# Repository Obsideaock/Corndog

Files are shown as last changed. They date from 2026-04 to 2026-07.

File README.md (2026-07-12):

# Project Corndog







> An open-source quadruped robot designed to make robotics accessible — one walking robot at a time.

Corndog Walking

Corndog started as a workaround to a college rule (no drones on campus → build a walking robot instead) and turned into a nearly two-year deep dive into robotics, kinematics, and control systems. Based on the open-source MicroSpot design and inspired by Boston Dynamics' Spot, it's a small quadruped with 3 degrees of freedom per leg, a full inverse kinematics stack, IMU feedback, and a growing set of behaviors.

**As featured on American Ninja Warrior Season 17**

---

## Current Status

| Feature | Status |
|---|---|
| Static walking gaits (forward/backward) | ✅ Working |
| Turn left / turn right | ✅ Working |
| Standing & balancing | ✅ Working |
| Inverse kinematics (IK) | ✅ Working |
| IMU feedback (BNO08X) | ✅ Working |
| Custom animations (dance, wave, handstand, etc.) | ✅ Working |
| Companion mode (shoulder perch) | ✅ Working |
| Steam Deck wireless control + video stream | ✅ Working |
| Dynamic gaits | 🔧 In progress |
| ML-Agents gait learning | 🔧 In progress (environment skeleton done) |
| Custom power PCB | 🔧 In progress |
| Kit available for purchase | 🔜 Coming soon |
| Assembly guide | 🔜 In progress |

---

## Build at a Glance

| Spec | Value |
|---|---|
| Size | ~15 inches |
| Legs | 4 (quadruped) |
| Degrees of freedom | 12 total (3 per leg) |
| Brain | Raspberry Pi 5 |
| Servo driver | Adafruit PCA9685 |
| Actuation range | 0–270° per servo |
| Power | LiPo battery + buck converter (custom PCB coming) |
| Construction | 3D printed (PLA) |
| Control | Tkinter GUI on-device, or Steam Deck over TCP |

---

## Estimated Cost

Corndog is open-source — you can print and source everything yourself. If you'd rather skip the work, a kit is coming soon through [OpenLonehollow](https://openlonehollow.com/Projects/corndog/corndog.html).

| Tier | What You Get | Estimated Price |
|---|---|---|
| **Printed Parts Only** | All 3D printed structural components | ~$60–80 |
| **Unassembled Kit** | Printed parts + all electronics | ~$450–500 |
| **Assembled & Calibrated** | Fully built, programmed, and ready to go | ~$800 |

Want to build it yourself from scratch? Everything you need is in this repo and the [assembly guide](https://openlonehollow.com/Projects/corndog/assembly-guide/index.html).

---

## Hardware

| Component | Notes | Example Link |
|---|---|---|
| Raspberry Pi 5 | Raspbian 64-bit | [Amazon](https://a.co/d/dEzpuJt) |
| Adafruit PCA9685 PWM Driver | I²C address 0x40 | [Adafruit](https://www.adafruit.com/product/815) |
| Servo Motors × 12 | 0–270°, pulse 500–2500 µs | [Amazon](https://a.co/d/4C4s5K8) |
| Adafruit BNO08X IMU | I²C address 0x4B | — |
| LiPo Battery + Power Module | Custom PCB solution coming | [Amazon](https://a.co/d/3LN6lL5) |
| I²C LCD Display | For status readout | — |
| Wires, headers, standoffs | Standard hobby hardware | — |

> A full Bill of Materials with exact quantities and sources is in progress and will be linked here.

---

## 3D Printed Parts

Most structural parts come from [KDY0523's Thingiverse design](https://www.thingiverse.com/thing:3445283), with reinforced legs from [mike4192's SpotMicro fork](https://github.com/mike4192/spotMicro).

Modifications and custom parts (like the shoulder harness for companion mode) are included in the `/3DModels` folder.

- All parts currently printed in **PLA**
- Experimented with ASA for joints (more strength) but it snapped under stress and PLA is easier to work with
- Thanks to **BTULab (where I work now) @ CU Boulder** for printing assistance

---

## Installation

Everything installs itself. On a fresh Raspberry Pi (Raspberry Pi OS
Bookworm 64-bit with desktop), open a terminal on the Pi and run:

```bash
curl -sSL https://raw.githubusercontent.com/Obsideaock/Corndog/main/installer/install.sh | bash
sudo reboot
```

That single line handles the apt packages, I2C, the Python environment,
the IK library, the `corndog` command, and the boot supervisor. To install
somewhere other than `~/Corndog`:

```bash
curl -sSL https://raw.githubusercontent.com/Obsideaock/Corndog/main/installer/install.sh | CORNDOG_DIR=/path/you/want bash
```

Full details in [Docs/USER_GUIDE.md](Docs/USER_GUIDE.md).

---

## Key Scripts

| Script | What it does |
|---|---|
| `main.py` | Core control: IK, all movements, Tkinter GUI |
| `SteamDeckCommunication.py` | Joystick control over TCP + MJPEG video stream |
| `MoveLib.py` | Movement library (aliased by SteamDeck script) |
| `gait_engine_app.py` | Gait engine module |
| `StartupLCD.py` | Boot supervisor + LCD display |
| `tools/align.py` | Assembly Part A: hold servos at the horn pose |
| `tools/calibrate.py` | Assembly Part B: trim joints + save calibration |
| `Flipper2.py` / `FlipperTed.py` | Flipper Zero integration |

---

## Setup & Calibration

Calibration is built in — no more editing angles by hand. During assembly:

```bash
corndog align       # Part A: before horns go on — holds every servo at
                    # the reference pose so you attach horns correctly
corndog calibrate   # Part B: after assembly, robot ON ITS BACK — nudge
                    # each joint to perfect, press s to save
```

The calibration lives in `~/.config/corndog/calibration.json` and survives
every software update. Details in
[Docs/USER_GUIDE.md](Docs/USER_GUIDE.md).

**Run**
```bash
corndog gui                 # GUI control (on-device)
corndog deck                # Steam Deck / remote control + video stream
# Stream available at http://<pi-ip>:8000/stream.mjpg
# Control on TCP port 65432
```

---

## Roadmap

- [x] Static walking gaits
- [x] Turn left / right
- [x] Inverse kinematics
- [x] IMU integration
- [x] Companion mode
- [x] Steam Deck control
- [ ] Assembly guide (in progress)
- [ ] Full BOM
- [ ] Custom power PCB
- [ ] Dynamic gaits
- [ ] ML-Agents gait training
- [ ] Web dashboard
- [ ] Kit launch

---

## Contributing

Issues and PRs are welcome — please use [GitHub Issues](https://github.com/Obsideaock/Corndog/issues) and follow existing code style. The project is licensed [CC BY 4.0](https://creativecommons.org/licenses/by/4.0/), so use and adapt freely with credit.

---

## Acknowledgements

- **[KDY0523](https://www.thingiverse.com/thing:3445283)** — original 3D design
- **[Mike4192](https://github.com/mike4192/spotMicro)** — reinforced legs and IK library
- **[BTULab @ CU Boulder](https://www.colorado.edu/atlas/btu-lab)** — 3D printing support

---

*Built by [Leo Heuring (Obsideaock)](https://openlonehollow.com) · [openlonehollow.com](https://openlonehollow.com)*

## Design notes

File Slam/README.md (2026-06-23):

# Corndog SLAM (v2.3)

Pure-Python 2D LiDAR SLAM for the Corndog quadruped. No ROS. Builds a live
occupancy-grid map and tracks where Corndog is on it while you walk it around.

Hector-style scan-to-map matching (the approach proven on the mike4192 SpotMicro
with an RPLidar A1), reimplemented in pure numpy and fused with your **BNO08x**
heading and the **gait engine's commanded velocity** as a motion prior.
Validated in simulation before any hardware: on a simulated two-room walk it
reconstructs the floorplan and tracks the path to ~12 cm mean error — a 92%
reduction vs dead-reckoning, at ~3x less CPU per scan than v1.

**v2.0 adds point-and-click navigation:** open the map in a browser, click a
spot, and Corndog plans a path (A* with adjustable wall clearance), drives there
following it, hard-stops for anything that appears in front, and arrives within
~10 cm. Plus a new canvas UI (pan/zoom, STOP, named "spots"), a 35x24 cm oriented
footprint box, and one-time relocalization when you resume a saved map.

**v2.1 adds keep-out awareness, autonomy, and a phone-friendly UI:**

- **No-go zones** — switch the UI to *No-go* mode and drag a box over anything
  that looks clear to the LiDAR but isn't safe (rugs, carpets, ledges). Zones are
  saved next to the map (`<map>.nogo.json`), so they persist across restarts, and
  the planner refuses to route through them. *Clear no-go* wipes them.
- **Stuck detection** — if Corndog is commanded forward but his SLAM pose barely
  advances for ~1.6 s, he assumes there's an unmapped obstacle, stamps a small
  keep-out blob just ahead (it joins the same persistent layer, shown in orange),
  backs up briefly, and re-plans around it.
- **Roam** — a toggle that sends him to random *reachable* spots (respecting the
  clearance), biased toward places he hasn't been recently. He only picks spots
  *connected to where he currently is through mapped open space* — he won't try to
  reach a previously-seen area by cutting across unmapped/unknown space. Good for
  "just go wander the apartment."
- **Route loops** — *Route* mode: tap several stops, hit *Start loop*, and he
  cycles them in order, repeating.
- **Phone-friendly UI** — one-finger drag pans, **two-finger pinch zooms**, a tap
  acts; the page no longer hijack-zooms on mobile and the buttons grow on small
  screens.
- **Clearance is now 15 cm** by default (was 10 cm).
- **Reset map** button (UI) — wipes the map, trail, saved spots and no-go zones
  and starts a fresh map from where he's standing, without restarting the script.
  Handy for re-running a test.

A single explicit goal click always overrides roam/route.

**v2.2 adds loop closure (background pose-graph optimisation):** the frontend's
scan-to-map matching drifts slowly over long runs — you see it as walls that
don't quite line up when you return to a room. A background thread now drops a
*keyframe* (pose + scan) every ~0.5 m, ties consecutive ones with odometry edges,
and when a new keyframe lands near an old one it confirms the revisit with a
scan-to-scan match against a clean *local* field (so global drift can't fool the
check). A confirmed revisit adds a loop constraint; the SE(2) pose graph is then
optimised (pure-numpy Gauss-Newton, no scipy) and the map is rebuilt from the
corrected keyframe poses, with the live pose and heading nudged to match. This is
the main lever for turning "arrives within ~10 cm *on the map*" into "within
~10 cm *physically*" on long multi-loop runs. It runs only when a revisit is
detected, throttled so the Pi isn't taxed. It is **off by default** (it can
disturb live tracking); enable with `--loopclose`.

**v2.3 — drift control + adaptive navigation:**

- **Motion-gated mapping.** Localisation and obstacle detection run every frame as
  always, but the map is only *written* when the robot is essentially stopped (and
  never mid-turn). A moving scan — especially during a turn, when the spinning
  LiDAR builds one revolution over ~180 ms — smears, and committing it thickens
  walls and feeds drift. Gating the write keeps walls crisp and, because you then
  localise against crisp walls, slows drift too. Default is near-stationary;
  `--map-while-moving` also maps during straight travel (still skips turns).
  The HUD's `mapskip` counter shows writes being held while moving.
- **Adaptive re-planning.** The follower no longer tracks a path drawn once at the
  start. It recomputes to the goal on the *current* map every ~1.5 s and whenever
  blocked, so a stale path (new wall, closed door, drift) is corrected instead of
  driven into — e.g. it will route to the open space beside a wall rather than
  pushing into it.
- **Roam stays local.** Roam now picks goals within a radius (default 3 m) of where
  he is, so he wanders the area instead of bolting to a far room, and only to spots
  reachable through mapped open space.
- **Live SLAM readout** in the HUD: `SLAM Hz · match score · gated · mapskip`, for
  diagnosing tracking at a glance.

## Where this folder goes
Drop the whole `Slam/` folder into your main Corndog directory, next to
`MoveLib.py`:

```
Corndog/                      <- your main folder
  MoveLib.py
  SteamDeckCommunication.py
  ... your other files
  Slam/                       <- this folder
    run_robot.py              <- run this ON THE ROBOT
    run_laptop.py             <- run this ON A LAPTOP to test (no hardware)
    validate_sim.py           <- optional offline accuracy check
    README.md
    core.py  occupancy.py  scan_match.py  render.py  sim.py
    nav.py  relocalize.py  waypoints.py  keepout.py  web_server.py
    slam_bridge.py  slam_lidar.py  slam_map_server.py  slam_app.py
```

The slam code reaches up one level to import `MoveLib` and
`SteamDeckCommunication`, so it must stay inside the main Corndog folder.

## Run it

**On the robot (the Pi):**
```
cd Slam
python3 run_robot.py                 # SLAM + your Steam Deck control
python3 run_robot.py --no-control    # SLAM only, robot stays still
python3 run_robot.py --load corndog_map.npz   # resume + relocalize in a saved map
python3 run_robot.py --control keys           # drive from the terminal (WASD)
```
Then open `http://<pi-ip>:8001/` in a browser. **Click anywhere on the map to
send Corndog there**; drag to pan, wheel to zoom, big red **STOP** to halt. Save
the current position as a named "spot" and tap it later to go back. You can still
drive Corndog manually (Steam Deck) and it maps as you walk. With `--load`, it
spends a few seconds at startup figuring out where it is in the loaded map before
tracking takes over.

**On a laptop first (no hardware needed):**
```
cd Slam
python3 run_laptop.py                 # then open http://localhost:8001/
python3 validate_sim.py               # prints metrics, writes slam_sim_result.png
```
`run_laptop.py` uses the exact same map view as the robot, fed by a simulator.

## Install
On the Pi: `pip3 install pillow pyrplidar --break-system-packages` — this code
uses your SYSTEM numpy (1.x) and needs no scipy. **Do NOT pip-install numpy or
scipy on the Pi:** numpy 2.x breaks `picamera2`/`simplejpeg` (the camera stack).

If you already did (you'll see a `numpy.dtype size changed` error), revert with:
```
pip3 uninstall -y numpy scipy
sudo apt install --reinstall python3-numpy
```
(your BNO08x / adafruit deps are already there via MoveLib).
On a laptop (for the demo): `pip3 install numpy pillow`.

## What it does (v2.0)
- Live **5 cm occupancy grid**, log-odds, with free-space carving so people
  walking through fade instead of becoming permanent walls.
- Pose from **scan matching** seeded by IMU yaw + commanded velocity.
- **Tilt gating**: scans taken mid-stride (body pitch/roll past a threshold)
  don't corrupt the map.
- **Live web map** at `:8001` — robot dot + heading, live scan (cyan) vs mapped
  walls (white), ~30 s trajectory trail (amber).
- **Save / load** maps (`.npz`), autosave every 15 s.
- Runs in the **same process** as your Steam Deck control (single MoveLib import,
  no hardware contention).
- **Faster matcher** (v2): the likelihood field is rebuilt only in a window
  around the robot and the search is vectorised — ~3x less CPU per scan than v1,
  with equal-or-better accuracy.
- **Click-to-go navigation** (v2): A* over the map with a configurable clearance
  (`ROBOT_RADIUS_M + DEFAULT_CLEARANCE_M` in `nav.py`, ~10 cm default) so paths
  keep off walls; pure-pursuit follower; forward-cone **obstacle hard-stop** that
  pauses and resumes; arrives within ~10 cm. Goals on walls, in unknown space, or
  unreachable are rejected with a reason.
- **Canvas web UI** (v2): crisp (no JPEG re-encode, lighter than the old MJPEG),
  click-to-go, pan/zoom, STOP, named waypoints, planned-path overlay, and a
  **35 x 24 cm oriented footprint box** so you can judge what he'll clear.
- **Relocalization** (v2): on `--load`, a one-time global "where am I" search
  places him in the saved map from a single scan.
- **LiDAR auto-resync** (v2): the A1's occasional startup byte-mismatch now
  retries/reconnects automatically instead of needing a restart.

## Delivered in v2.1
No-go zones, stuck-detection with auto-obstacle + reroute, roam, route loops, the
phone-friendly UI, and 15 cm clearance (see the v2.1 summary up top). Roam covers
most of what "autonomous explore" was meant to do, and stuck-detection is a first
cut at dynamic re-routing around things the map didn't know about.

## Delivered in v2.2
**Loop closure + pose-graph optimisation** (see the v2.2 summary up top) — removes
the slow global drift on long multi-loop runs, the main thing between "arrives
within ~10 cm *on the map*" and "within ~10 cm *physically*."

## Next
Tighter integration of the loop-corrected map with relocalisation, and optional
sub-5 cm resolution (still deferred on purpose — compute budget — and won't change
silently).

## Bring-up calibration (once, on the robot)
Two sign conventions can't be known until it's on Corndog. Each is a one-line flip:

1. **Heading sense** — `YAW_SIGN` in `slam_bridge.py`. Turn Corndog ~90° left in
   place; if the map rotates the wrong way, set it to `-1.0`.
2. **LiDAR direction** — `LIDAR_CCW` in `slam_lidar.py`. If the map comes out
   mirrored (left/right flipped), toggle it. Use `ANGLE_OFFSET_DEG` if 0° isn't
   dead-ahead.
3. **Velocity scale** — `VEL_SCALE` in `slam_bridge.py`. Walk a measured 2 m; if
   the trail reads long/short, scale it. (Minor — the matcher fixes translation.)

Tilt gate (`tilt_gate_deg`, default 9°) and log-odds rates live in `core.py` /
`occupancy.py` for tuning to your gait.

## File map
```
core.py            SlamCore: motion prior + matching + map + trajectory (hardware-agnostic)
occupancy.py       log-odds grid, ray carving, save/load
scan_match.py      multi-res correlative scan matching + likelihood field
render.py          grid + overlays -> image (shared by web view + sim)
sim.py             hardware-free simulator (floorplan, foot-slip, body bob)
slam_bridge.py     [robot] BNO08x + gait engine -> motion hint
slam_lidar.py      [robot] RPLIDAR reader thread
nav.py             A* planner (15 cm clearance, keep-out aware) + pure-pursuit follower,
                   obstacle stop, route loops, roam, stuck-detection + reroute
relocalize.py      global "where am I" search for a loaded map
web_server.py      canvas/JSON web UI: Go / Route / No-go modes, Roam toggle, pinch-zoom,
                   click-to-go, STOP, waypoints, footprint box
waypoints.py       named map locations, saved next to the map
keepout.py         persistent no-go zones + auto-obstacles, saved next to the map
pose_graph.py      SE(2) pose-graph Gauss-Newton optimiser (pure numpy, no scipy)
loop_closure.py    keyframe graph: revisit detection + optimise + map rebuild (background)
slam_map_server.py old MJPEG map view (superseded by web_server.py; kept as fallback)
slam_app.py        [robot] launcher internals (called by run_robot.py)
run_robot.py       ON-ROBOT entry point
run_laptop.py      laptop demo (no hardware) — full click-to-navigate in sim
validate_sim.py    offline accuracy check
```

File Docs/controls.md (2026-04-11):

# Controls Guide

This page covers the current and planned control methods for Corndog.

## Current control methods

### Steam Deck control

Launch with:

```bash
python3 SteamDeckCommunication.py
```

### Local control / experimentation

Launch with:

```bash
python3 main.py
```

### Flipper Zero control

Flipper Zero support is included in the project and is currently considered effectively working.

## Planned additions

- Control mapping details
- Pairing/setup notes
- Streaming instructions
- Troubleshooting latency and connection issues

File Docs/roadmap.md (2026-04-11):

# Roadmap

## In progress

- Improved IK walking
- IK turning
- Machine learning environment
- Updated battery solution

## Planned

- Wiring guide
- Full assembly guide
- BOM / sourcing documentation
- Better beginner documentation
- Expanded machine learning workflow
- Autonomous behavior experiments
- More polished kit/site-style documentation structure over time

## Philosophy

Corndog is meant to stay fun, open, and educational while becoming easier to reproduce over time.

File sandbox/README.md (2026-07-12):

# Sandbox — your folder

Anything you put in here is YOURS. Updates never touch it, `corndog update
--force` never deletes it, and it won't show up as "local changes" that
block updates.

Start by copying the example (it shows every movement command):

    cp sandbox/example.py sandbox/mytest.py

Then write your experiments and run them with:

    corndog run sandbox/mytest.py

Everything in the main Corndog folders belongs to the official software —
if you edit those files, updates will refuse until you either undo your
edits or run `corndog update --force` (which resets them). This folder is
the safe place instead. (One exception: `example.py` here belongs to
the official software — copy it rather than editing it directly.)

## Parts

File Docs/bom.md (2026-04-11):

# Bill of Materials

## Estimated build cost

Estimated build cost is **around $500 USD**, depending on parts sourcing.

## Core components

| Component | Notes |
|---|---|
| Raspberry Pi 5 | Main compute platform |
| PCA9685 servo driver | PWM control |
| 12 servos | Main actuation |
| Battery + power hardware | Current setup in transition |
| Wiring, headers, standoffs, misc. hardware | Supporting hardware |

## Status

A full sourcing list with direct part recommendations and cost breakdowns is coming soon.

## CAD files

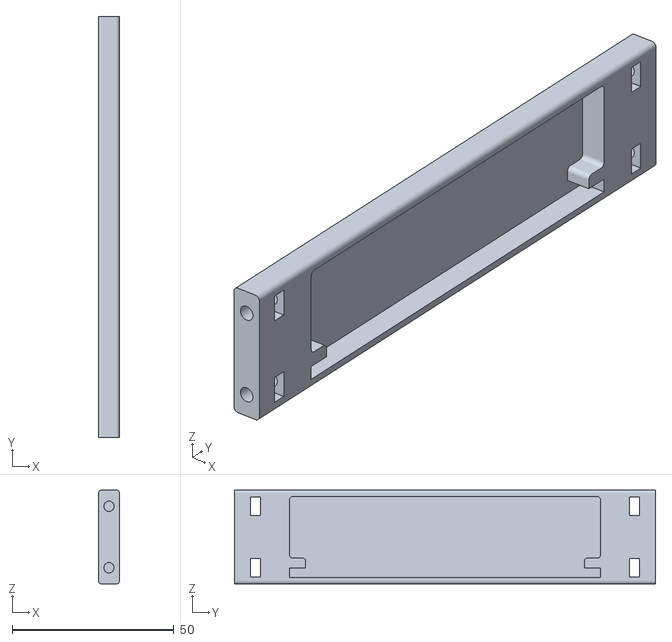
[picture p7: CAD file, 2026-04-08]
3DModels/non-mega_L_side_plate.stl
6.50 x 130.0 x 29.0

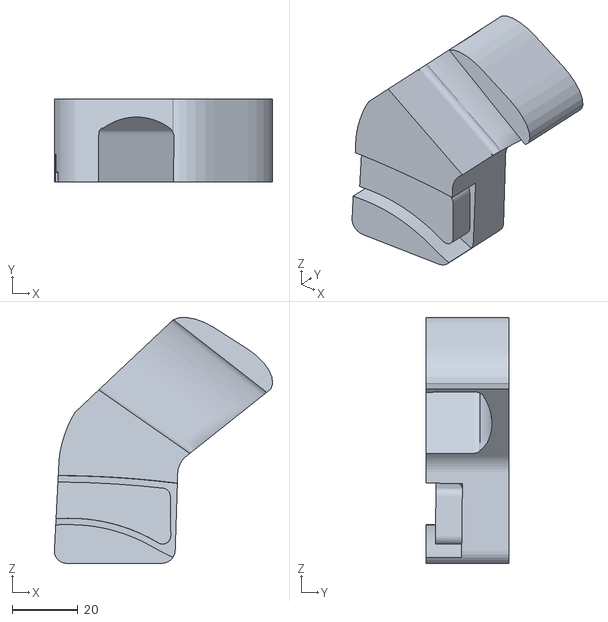
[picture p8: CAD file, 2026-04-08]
3DModels/CornDog holder Elbow.stl
66.2 x 25.2 x 74.6

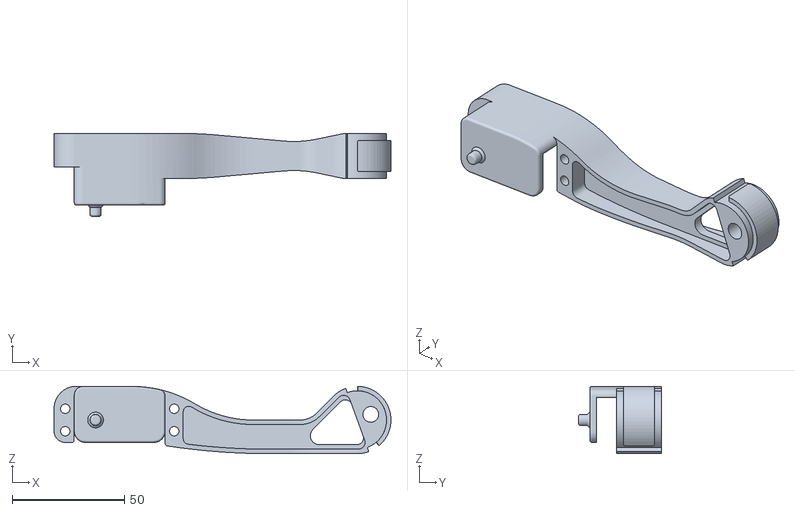
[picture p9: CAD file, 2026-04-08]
3DModels/L_wrist_mg.stl
150.0 x 36.9 x 30.0

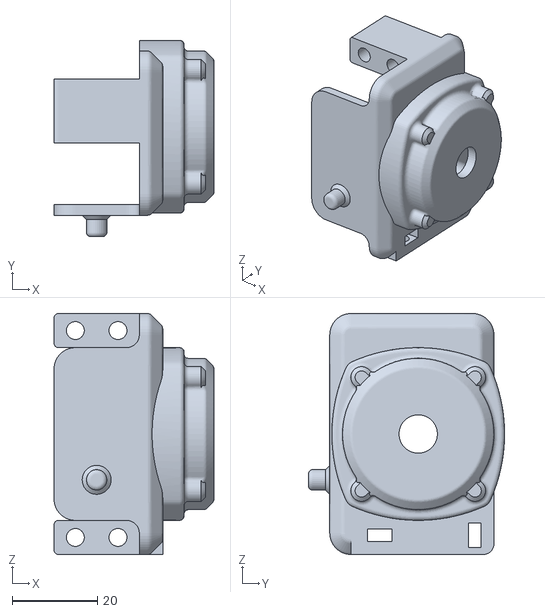
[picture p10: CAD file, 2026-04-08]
3DModels/L_arm_joint_cls_for_shoulder_reinforcement.STL
37.5 x 46.0 x 56.5

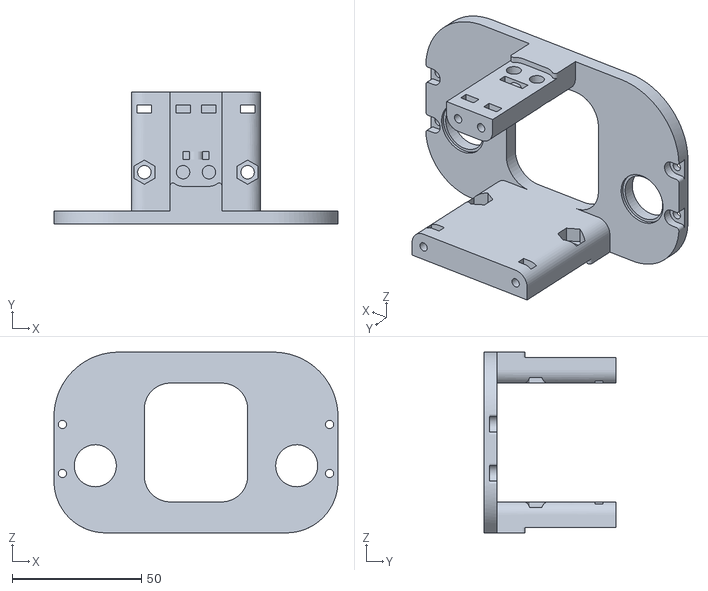
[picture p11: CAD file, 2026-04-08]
3DModels/I_shoulder_mg.stl
110.0 x 51.0 x 70.0

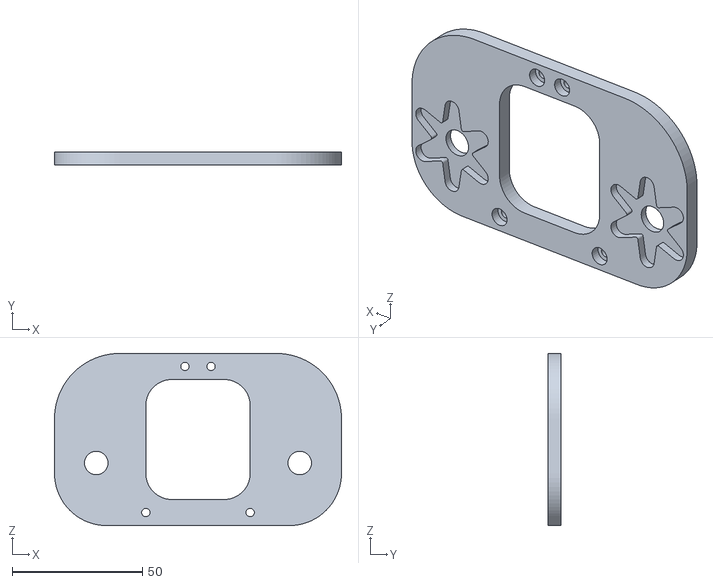
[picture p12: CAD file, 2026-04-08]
3DModels/O_shoulder.stl
110.0 x 5.00 x 66.0

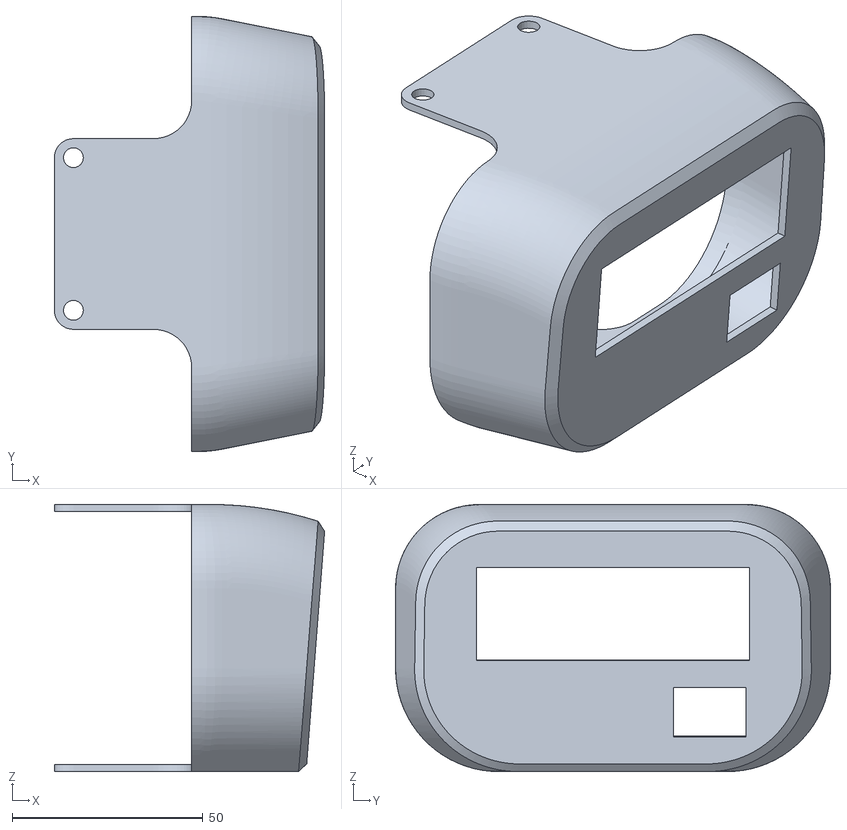
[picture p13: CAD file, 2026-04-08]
3DModels/RearLong.stl
70.8 x 114.0 x 70.0

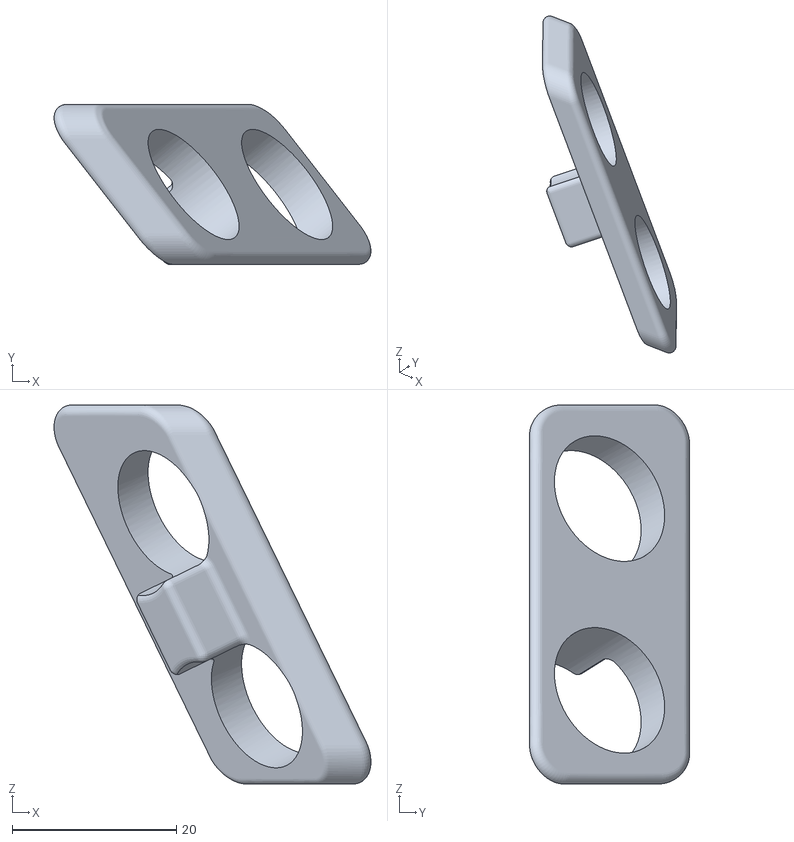
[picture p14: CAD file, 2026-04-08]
3DModels/L_ultra_sonic.stl
38.6 x 19.5 x 46.2

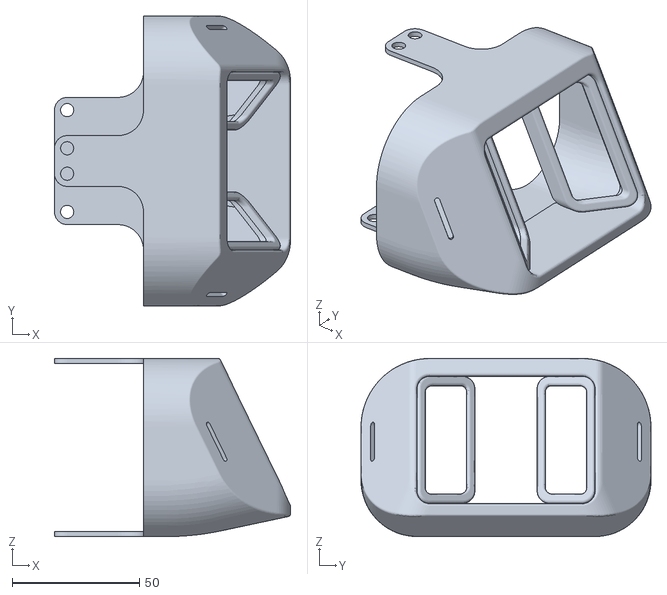
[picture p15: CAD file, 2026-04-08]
3DModels/F_cover.stl
92.8 x 114.0 x 70.0

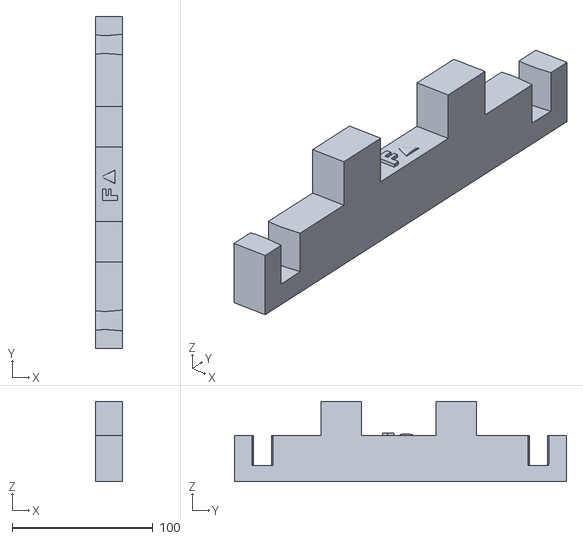
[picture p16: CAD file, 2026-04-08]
3DModels/CornDog holder Wrist.stl
19.0 x 235.5 x 57.0

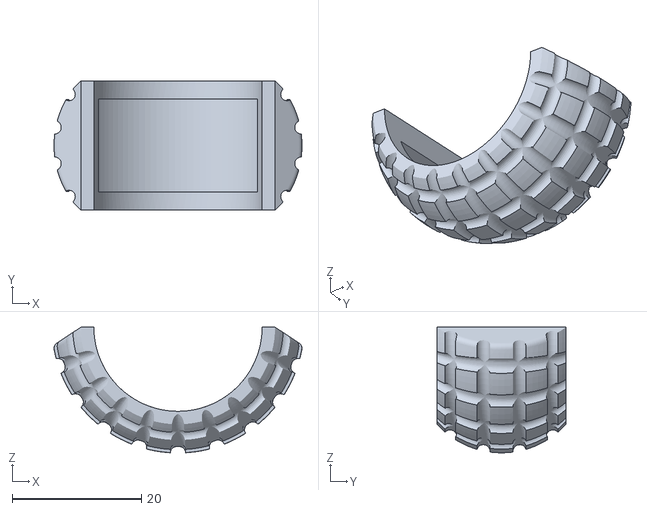
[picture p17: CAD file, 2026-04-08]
3DModels/foot.stl
38.3 x 20.0 x 19.4

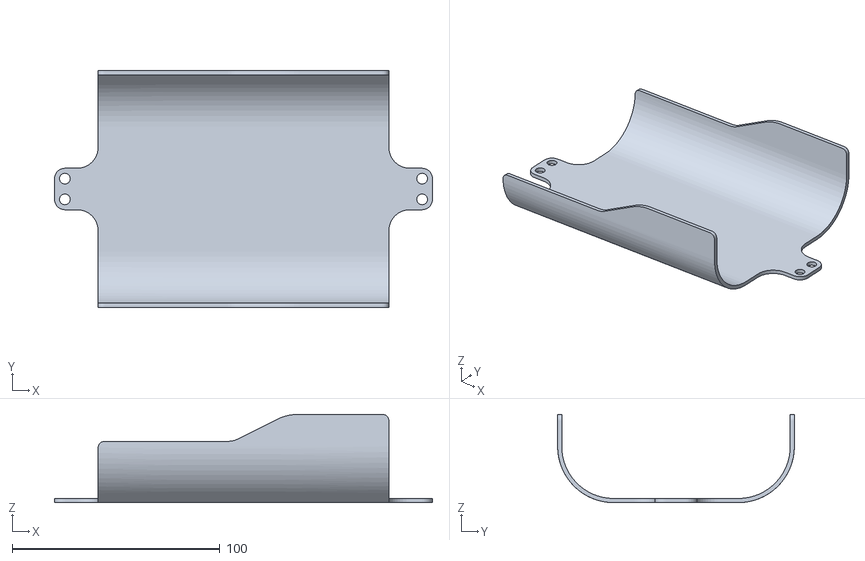
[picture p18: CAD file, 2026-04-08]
3DModels/BottomLong.stl
182.0 x 114.0 x 42.5

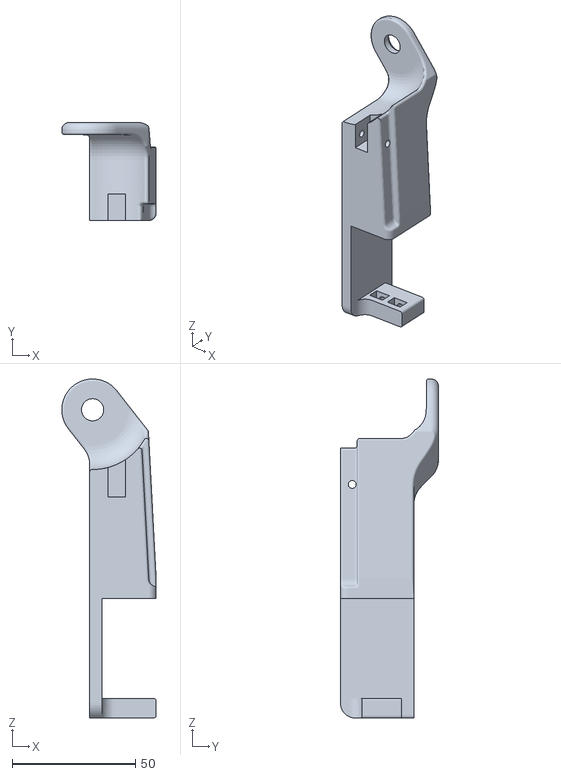
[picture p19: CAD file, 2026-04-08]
3DModels/R_arm_mg.stl
38.2 x 39.8 x 137.4

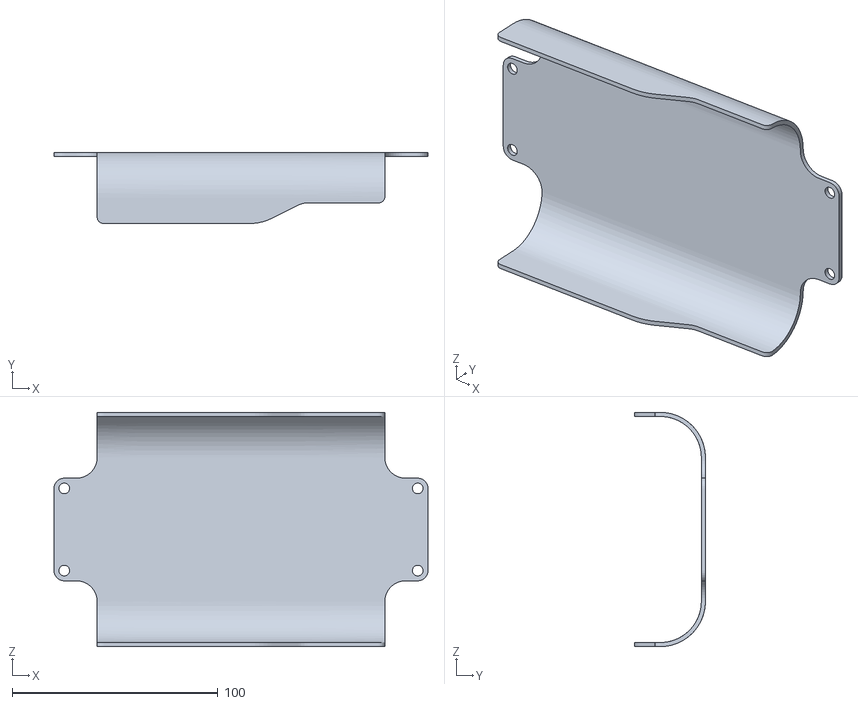
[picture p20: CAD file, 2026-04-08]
3DModels/TopLong.stl
182.0 x 34.5 x 114.0

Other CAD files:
3DModels/R_side_plate.stl
3DModels/R_ultra_sonic.stl
3DModels/RearLong(LOGO).stl
3DModels/L_arm_cover_for_shoulder_reinfrocement.STL

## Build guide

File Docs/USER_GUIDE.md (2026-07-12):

# Corndog User Guide — install, update, and every command

## How you use Corndog

Everything happens **on the robot itself**. You remote into your Corndog's
Raspberry Pi — Raspberry Pi Connect is the easiest way (SSH or VNC work
too) — and use its terminal to run commands. If you want to poke at the
code, Geany (preinstalled on Raspberry Pi OS) is right there on the Pi's
desktop.

When you're *not* remoted in, the robot still works on its own: a
supervisor service starts at boot and handles the Steam Deck and Flipper
control modes automatically.

## Installing (one line)

On a fresh Raspberry Pi (Raspberry Pi OS Bookworm 64-bit with desktop),
open a terminal on the Pi and run:

```bash
curl -sSL https://raw.githubusercontent.com/Obsideaock/Corndog/main/installer/install.sh | bash
```

It sets up everything: system packages, I2C, the Python environment, the
`corndog` command, and the boot supervisor. When it finishes:

```bash
sudo reboot
```

That's it. The installer is safe to re-run any time — re-running repairs a
broken install. It installs to `~/Corndog` by default; to put it somewhere
else, add `CORNDOG_DIR`:

```bash
curl -sSL https://raw.githubusercontent.com/Obsideaock/Corndog/main/installer/install.sh | CORNDOG_DIR=/path/you/want bash
```

## Building & calibrating (the two assembly tools)

**Part A — before assembly, before horns go on:**

```bash
corndog align
```

Holds every servo at the correct angle so you can press the horns on in the
right orientation, and shows which servo plugs into which channel so you
can label the wires.

**Part B — after the robot is fully assembled:**

```bash
corndog calibrate
```

Lay him on his back first (all motors turn on the moment you confirm!).
Nudge each joint until it's perfectly straight / 90 degrees, press `s` to
save, `q` to quit. Done — the robot now knows its true home position
forever. You never need to run this again unless you rebuild a leg.

## Your sandbox (write your own scripts safely)

The folder `~/Corndog/sandbox/` is **yours**. Put your own experiments and
scripts there — updates never touch it, and files there never block an
update. Run them with:

```bash
corndog run sandbox/my_script.py
```

Everything *outside* the sandbox belongs to the official software. You can
read it and learn from it freely, but if you edit those files, `corndog
update` will refuse until you undo the edits or `--force` past them.

## Using Geany (the code editor on the Pi)

If you like pressing Run inside Geany instead of typing commands: open any
Python file, go to **Build → Set Build Commands**, and set the Execute
command to:

```
corndog run "%d/%f"
```

Now F5 runs the current file the proper way — supervisor paused around it,
right Python environment, no password prompts.

## Everyday commands

| Command | What it does |
|---|---|
| `corndog status` | Overview: version, calibration, supervisor state |
| `corndog gui` | On-device control panel |
| `corndog deck` | Steam Deck remote-control mode |
| `corndog gait` | Gait tuning app (sliders for how he walks) |
| `corndog run <file.py>` | Run any script from the repo |
| `corndog supervisor status` | Is the boot service running? |
| `corndog supervisor logs` | Live logs from the boot service |
| `corndog update` | Get the latest Corndog software |
| `corndog uninstall` | Remove the service + command (keeps your files) |

**Always launch scripts through `corndog`** (either a named command or
`corndog run yourscript.py`) rather than plain `python3`. The boot
supervisor owns the servos, and the `corndog` command pauses it
automatically and brings it back when you're done — even if the script
crashes. If you really want to run something by hand:

```bash
corndog supervisor stop
~/Corndog/venv/bin/python yourscript.py
corndog supervisor start
```

## Updating

```bash
corndog update
```

Pulls the newest release and restarts the supervisor. Your calibration and
settings live in `~/.config/corndog/` and are never touched by updates.

If you experimented with the official files in Geany and the update refuses
because of your edits:

```bash
corndog update --force
```

This resets every official file to the release and clears out stray files —
but your `sandbox/` folder and your calibration/settings in
`~/.config/corndog/` always survive. (This is also the "put everything back
the way it should be" button.)

## If something's wrong

1. `corndog status` — is calibration present? Is the supervisor running?
2. `corndog supervisor logs` — watch what the boot service is doing.
3. Re-run the installer — it repairs missing pieces:
   `bash ~/Corndog/installer/install.sh`
4. Servos acting strange? Re-run `corndog calibrate` (on his back!).
5. Broke something while experimenting? `corndog update --force` puts
   every official file back to the release (sandbox + calibration kept).

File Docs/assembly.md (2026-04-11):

# Assembly Guide

This guide will walk through the full mechanical assembly process for Corndog.

## Status

Coming soon.

## Planned sections

- Printed parts overview
- Servo installation
- Leg assembly order
- Body assembly
- Mounting electronics
- Common assembly mistakes
- Final pre-power checks

## Notes

Right now, all of the printed parts used in the current build are included in the repo, but a beginner-friendly assembly guide has not been written yet.

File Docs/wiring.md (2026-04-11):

# Wiring Guide

This page will document the wiring and power layout for Corndog.

## Status

Coming soon.

## Planned sections

- Raspberry Pi connections
- PCA9685 wiring
- Servo power distribution
- Battery and power notes
- LCD / accessory wiring
- Cable routing recommendations
- Safety notes

## Notes

Wiring documentation is being held until the updated battery solution is finalized so the guide reflects the current intended setup.

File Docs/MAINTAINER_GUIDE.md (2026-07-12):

# Corndog Maintainer Guide (for Leo)

How this setup thinks about YOUR workflow:

- **Your dog is the dev machine.** You remote in (Pi Connect), edit with
  Geany or the terminal, and run things right there. Your working copy in
  `~/Desktop/RobotOperationScripts/Corndog` is the source of truth — you never *pull* updates, you only
  *push* them.
- Your dog lives on the `experimental` branch. Users live on `main`.
- `corndog update` is a **users-only** command. You are upstream; there is
  nothing for you to update from.
- Your live edits are what runs: `corndog gui`, `corndog run`, etc. launch
  the files in your working copy (with the supervisor auto-paused), so the
  edit → test loop is just "save in Geany, run the command."

---

## 1. DO THIS RIGHT NOW (one-time setup, on the dog)

```bash
cd ~/Desktop/RobotOperationScripts/Corndog

# 1. sanity check
git status

# 2. commit and push everything to main
git add -A
git commit -m "Add installer, calibration tools, config system, guides"
git push origin main

# 3. create your experimental branch and stay on it (one time only)
git checkout -b experimental
git push -u origin experimental

# 4. run the installer FROM INSIDE the repo — it detects it's being run
#    from a cloned repo and installs THAT copy in place (no second clone),
#    keeping whatever branch you're on
bash installer/install.sh

# 5. reboot once (hardware group changes + supervisor service start)
sudo reboot

# 6. after remoting back in, check everything — branch should say
#    experimental
corndog status
```

Notes:

- **Remove your old StartupLCD autostart.** The installer added a systemd
  service for it; whatever you used before (crontab, rc.local, an autostart
  .desktop file) must go, or two copies will fight over the GPIO.
  (`crontab -e`, check `/etc/rc.local`, check `~/.config/autostart/`.)
- Your old venv (`robo`) is untouched. The install made its own at
  `<repo>/venv`. Delete `robo` whenever you're confident.
- **If `git push` asks for a password:** GitHub needs a token or SSH key on
  the dog (one time). Easiest is the GitHub CLI:
  ```bash
  sudo apt install gh
  gh auth login        # pick GitHub.com -> HTTPS -> login with browser
  ```
  After that, pushes from the dog just work.

---

## 2. Day-to-day development (all on the dog)

You're always on `experimental` (`corndog status` confirms). The loop is:

```bash
# edit in Geany / terminal ... then test immediately:
corndog gui                      # or corndog run tests/whatever.py
# the command runs YOUR edited files, supervisor paused around it

# happy with it? snapshot it:
git add -A
git commit -m "what you changed"
git push origin experimental
```

That's the whole loop. Commit small and often — every commit is a restore
point (`git log --oneline` to see them, `git checkout <hash> -- file.py`
to bring an old version of a file back).

Two special cases:

- **Geany build command:** replace your old Execute command
  (`.../robo/bin/python3.11 "%f"`) with:
  ```
  corndog run "%d/%f"
  ```
  (Build → Set Build Commands → Execute.) F5 now runs whatever file you're
  editing through the launcher: correct venv, supervisor auto-paused, no
  password prompt (the installer grants passwordless sudo for exactly the
  three supervisor commands and nothing else). Works for files anywhere in
  the repo, including `sandbox/`.

- **You edited `installer/corndog` itself** (the launcher): the copy in
  `~/.local/bin` doesn't update by itself for you. Refresh it:
  ```bash
  cp installer/corndog ~/.local/bin/corndog   # from the repo folder
  ```
- **You edited `installer/install.sh`:** nothing to do — users always fetch
  it fresh from GitHub via the curl line.

---

## 3. Releasing to users: `experimental` -> `main`

When a feature is solid, still on the dog:

```bash
cd ~/Desktop/RobotOperationScripts/Corndog
git checkout main
git merge experimental           # bring in your tested work
git push origin main
git checkout experimental        # IMPORTANT: come back to your branch
git merge main                   # keep experimental current (fast-forward)
git push origin experimental
```

Heads-up: for the minute you're on `main`, the code on the dog IS main —
don't do the branch dance mid-drive-session. Coming back to `experimental`
restores your world exactly.

Users get the release next time they run `corndog update`. Their
calibration in `~/.config/corndog/` is never touched.

Hotfix that must skip experimental (rare):

```bash
git checkout main
# ... fix ...
git add -A && git commit -m "hotfix: ..." && git push origin main
git checkout experimental && git merge main && git push origin experimental
```

---

## 4. Generating the master tables (one-time, on your calibrated dog)

```bash
corndog run tools/master_finder.py
```

He snaps to HOME on confirm (on his back!). Nudge every joint until he's in
the reference pose (all straight / 90 deg), press `g`, quit. It prints a
complete replacement for `tools/master_tables.py` and saves a copy at
`~/.config/corndog/master_tables_generated.py`. Paste it over
`tools/master_tables.py` in Geany, sanity-check the theta estimates (clean
numbers like 0 / ±90 if the pose is true — if they're not clean, the current
IK mapping is suspect and worth a look), then commit and push. From that
moment `corndog align` and `corndog calibrate` are fully armed for builders.

---

## 5. Cheat sheet

| I want to... | Command (on the dog) |
|---|---|
| test my current edits | `corndog gui` / `corndog run <file>` — edits are live |
| snapshot work-in-progress | `git add -A && git commit -m "..." && git push origin experimental` |
| release to everyone | section 3 branch dance |
| see branch / commit / service / calibration | `corndog status` |
| pause / resume the supervisor manually | `corndog supervisor stop` / `start` |
| watch supervisor logs | `corndog supervisor logs` |
| refresh the launcher after editing it | `cp installer/corndog ~/.local/bin/corndog` |

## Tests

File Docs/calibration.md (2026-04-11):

# Calibration Guide

Calibration is one of the most important parts of getting Corndog working correctly.

## Current workflow

### 1. Find servo endpoints

Run:

```bash
python3 SingularMotortest.py
```

Use this to determine the usable range for each servo.

### 2. Set the standing pose

- Place the robot upside down
- Manually adjust each joint
- Find a pose where all joints are aligned consistently
- Save those values into `servo_home`

### 3. Review mapping values

Check `MAPPING` and `CHANNEL_MAP` in `main.py`.

### 4. Tune offsets

Adjust offsets until the robot’s actual physical home pose matches the intended pose.

## Example offset adjustment

```text
Leg 3 planned deltas:
{7: 10.3512659818415784, 5: -6.30598966999280464, 1: -30.17742776376383063}
```

Before:

```python
3: {
  1: {'sign': +1, 'offset': 45},
  2: {'sign': -1, 'offset': 83},
  3: {'sign': -1, 'offset': 131}
}
```

After:

```python
3: {
  1: {'sign': +1, 'offset': 35},
  2: {'sign': -1, 'offset': 89},
  3: {'sign': -1, 'offset': 161}
}
```

## Status

This page will be expanded with photos, better examples, and troubleshooting notes.

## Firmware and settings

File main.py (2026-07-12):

import time
import board
import busio
from adafruit_pca9685 import PCA9685
from adafruit_motor import servo
from gpiozero import OutputDevice
import sys
import tkinter as tk
from math import sqrt, sin, cos, tan, asin, acos, atan, degrees
import math
import numpy as np

# --- IMU setup ---
from adafruit_bno08x.i2c import BNO08X_I2C
from adafruit_bno08x import (
	BNO_REPORT_ACCELEROMETER,
	BNO_REPORT_GYROSCOPE,
	BNO_REPORT_MAGNETOMETER,
	BNO_REPORT_LINEAR_ACCELERATION,
	BNO_REPORT_GRAVITY,
	BNO_REPORT_ROTATION_VECTOR,
	BNO_REPORT_GAME_ROTATION_VECTOR,
	BNO_REPORT_GEOMAGNETIC_ROTATION_VECTOR,
)
from spot_micro_kinematics.spot_micro_stick_figure import SpotMicroStickFigure
# import the low-level utilities:
from spot_micro_kinematics.utilities.transformations import homog_transxyz, homog_rotxyz, ht_inverse
from spot_micro_kinematics.utilities.spot_micro_kinematics import (
	t_rightback, t_rightfront, t_leftfront, t_leftback, ikine
)

from pathlib import Path as _Path
_REPO_ROOT = _Path(__file__).resolve().parent
sys.path.insert(0, str(_REPO_ROOT))            # for `lcd` / `drivers`
sys.path.insert(0, str(_REPO_ROOT / "tools"))  # for corndog_config
from lcd import lcd_library as lcd
from corndog_config import load_calibration as _load_calibration

# Initialize I2C bus and PCA9685 module
i2c = busio.I2C(board.SCL, board.SDA)
pca = PCA9685(i2c)
pca.frequency = 50

OE_PIN = 22
output_enable = OutputDevice(OE_PIN, active_high=False)

# Define the servo channels and positions
servo_channels = [0, 1, 4, 5, 6, 7, 8, 9, 10, 11, 14, 15]
# servo_home + IK mapping come from ~/.config/corndog/calibration.json
# (factory values if the robot hasn't been calibrated yet)
_CAL = _load_calibration()
servo_home = dict(_CAL["servo_home"])
TURN_SCALE = 0.2
LEFT_CHANNELS  = {15, 11,  0,  4}  # FL ankle, FL thigh, BL ankle, BL thigh
RIGHT_CHANNELS = {14, 10,  1,  5}  # FR ankle, FR thigh, BR ankle, BR thigh

# Initialize servos on the specified channels
servos = {channel: servo.Servo(pca.channels[channel]) for channel in servo_channels}
for channel in servos:
	servos[channel].set_pulse_width_range(500, 2500)
	servos[channel].actuation_range = 270

i2c = busio.I2C(board.SCL, board.SDA)
bno = BNO08X_I2C(i2c, address=0x4B)

# Enable all the reports
_features = [
	BNO_REPORT_ACCELEROMETER,
	BNO_REPORT_GYROSCOPE,
	BNO_REPORT_MAGNETOMETER,
	BNO_REPORT_LINEAR_ACCELERATION,
	BNO_REPORT_GRAVITY,
	BNO_REPORT_ROTATION_VECTOR,
	BNO_REPORT_GAME_ROTATION_VECTOR,
	BNO_REPORT_GEOMAGNETIC_ROTATION_VECTOR,
]
for f in _features:
	bno.enable_feature(f)

# Offsets for zeroing
q_grav_correction = (1.0, 0.0, 0.0, 0.0)
acc_offset = (0.0, 0.0, 0.0)
gyro_offset = (0.0, 0.0, 0.0)
mag_offset = (0.0, 0.0, 0.0)
linacc_offset = (0.0, 0.0, 0.0)
# we will use quaternions for orientation-based zeroing
quat_offset = (1.0, 0.0, 0.0, 0.0)
game_quat_offset = (1.0, 0.0, 0.0, 0.0)
geomag_quat_offset = (1.0, 0.0, 0.0, 0.0)

def quat_inverse(q):
	w, x, y, z = q
	return (w, -x, -y, -z)

def quat_multiply(a, b):
	w1, x1, y1, z1 = a
	w2, x2, y2, z2 = b
	return (
		w1*w2 - x1*x2 - y1*y2 - z1*z2,
		w1*x2 + x1*w2 + y1*z2 - z1*y2,
		w1*y2 - x1*z2 + y1*w2 + z1*x2,
		w1*z2 + x1*y2 - y1*x2 + z1*w2,
	)

def quaternion_between_vectors(a, b):
	ax, ay, az = a
	bx, by, bz = b
	# cross product
	cx = ay*bz - az*by
	cy = az*bx - ax*bz
	cz = ax*by - ay*bx
	# dot product
	dot = ax*bx + ay*by + az*bz
	# norms
	na = math.sqrt(ax*ax + ay*ay + az*az)
	nb = math.sqrt(bx*bx + by*by + bz*bz)
	if na == 0 or nb == 0:
		return (1.0, 0.0, 0.0, 0.0)
	# build quaternion (w, x, y, z)
	w = na*nb + dot
	x, y, z = cx, cy, cz
	# handle the 180degrees corner case if vectors are opposite
	if w < 1e-6 * na * nb:
		# pick an arbitrary orthogonal axis
		if abs(ax) > abs(az):
			x, y, z = -ay, ax, 0.0
		else:
			x, y, z = 0.0, -az, ay
		w = 0.0
	# normalize
	norm = math.sqrt(w*w + x*x + y*y + z*z)
	return (w/norm, x/norm, y/norm, z/norm)

def rotate_vector_by_quat(v, q):
	# rotates vector v by quaternion q
	q_conj = quat_inverse(q)
	# represent v as quaternion with zero scalar part
	vx, vy, vz = v
	v_q = (0.0, vx, vy, vz)
	tmp = quat_multiply(q, v_q)
	res = quat_multiply(tmp, q_conj)
	return (res[1], res[2], res[3])

MOUNT_RPY_DEG = (-2.0, -2.0, 0.0)  # (roll, pitch, yaw) of the IMU relative to the robot body, in degrees

def euler_deg_to_quat(roll_deg, pitch_deg, yaw_deg):
	r = math.radians(roll_deg); p = math.radians(pitch_deg); y = math.radians(yaw_deg)
	cr, sr = math.cos(r/2), math.sin(r/2)
	cp, sp = math.cos(p/2), math.sin(p/2)
	cy, sy = math.cos(y/2), math.sin(y/2)
	# quaternion (w, x, y, z)
	return (
		cy*cp*cr + sy*sp*sr,
		cy*cp*sr - sy*sp*cr,
		cy*sp*cr + sy*cp*sr,
		sy*cp*cr - cy*sp*sr,
	)

MOUNT_Q = euler_deg_to_quat(*MOUNT_RPY_DEG)

def zero_imu():
	"""Repurposed: do NOT zero to current pose; just apply the fixed, known mount offset."""
	global MOUNT_Q
	MOUNT_Q = euler_deg_to_quat(*MOUNT_RPY_DEG)

# Wrapper getters
def get_acceleration():
	x, y, z = bno.acceleration
	ox, oy, oz = acc_offset
	return (x-ox, y-oy, z-oz)

def get_gyroscope():
	x, y, z = bno.gyro
	ox, oy, oz = gyro_offset
	return (x-ox, y-oy, z-oz)

def get_magnetic():
	x, y, z = bno.magnetic
	ox, oy, oz = mag_offset
	return (x-ox, y-oy, z-oz)

def get_linear_acceleration():
	x, y, z = bno.linear_acceleration
	ox, oy, oz = linacc_offset
	return (x-ox, y-oy, z-oz)

def get_quaternion():
	q = bno.quaternion
	inv0 = quat_inverse(quat_offset)
	return quat_multiply(inv0, q)

def get_game_quaternion():
	q = bno.game_quaternion
	inv0 = quat_inverse(game_quat_offset)
	return quat_multiply(inv0, q)

def get_geomagnetic_quaternion():
	q = bno.geomagnetic_quaternion
	inv0 = quat_inverse(geomag_quat_offset)
	return quat_multiply(inv0, q)

def get_gravity():
	# rotate raw gravity into your zeroed frame:
	g = bno.gravity
	gx, gy, gz = rotate_vector_by_quat(g, MOUNT_Q)
	return (gx/9.80665, gy/9.80665, gz/9.80665)

def initialize_servo_angles():
	"""
	Initializes the servo_angles dictionary based on the initial standing positions.
	This function should be called once at the start of the program.
	"""
	servo_standing = servo_home
	global servo_angles
	servo_angles = {channel: angle for channel, angle in servo_standing.items()}

def move_motors(movements, delay=0.01, speed_multiplier=10):
	def clamp_angle(angle):
		return max(0, min(270, angle))  # 0-270

	global servo_angles

	# Extract channels and relative angles
	channels = list(movements.keys())
	relative_angles = list(movements.values())

	# Current angles
	current_angles = [
		servo_angles[channel] if channel in servo_angles
		else servo_standing[channel]
		for channel in channels
	]

	# Target angles (with clamp)
	target_angles = [
		clamp_angle(cur + rel)
		for cur, rel in zip(current_angles, relative_angles)
	]

	# Figure out the maximum steps (float, not int yet)
	max_step_count = max(
		abs(t - c) * 10  # 10 steps per degree
		for t, c in zip(target_angles, current_angles)
	)
	# Convert to int after dividing by speed
	adjusted_step_count = max(1, int(round(max_step_count / speed_multiplier)))

	# Increments
	increments = []
	for t, c in zip(target_angles, current_angles):
		if adjusted_step_count != 0:
			increments.append((t - c) / adjusted_step_count)
		else:
			increments.append(0)

	# Initialize a dict of current positions
	current_positions = dict(zip(channels, current_angles))

	# Move motors in small increments
	for step in range(adjusted_step_count):
		for i, channel in enumerate(channels):
			if increments[i] != 0:
				new_angle = current_positions[channel] + increments[i]
				new_angle = clamp_angle(new_angle)
				current_positions[channel] = new_angle
				servo_angles[channel] = new_angle
				servos[channel].angle = new_angle
		time.sleep(delay)

	# Optional tiny correction step to ensure final angle
	for i, channel in enumerate(channels):
		servo_angles[channel] = target_angles[i]
		servos[channel].angle = target_angles[i]

def stand_up():
	def set_motor_angles(channels, positions):
		for channel in channels:
			servos[channel].angle = positions[channel]
		time.sleep(0.5)  # Wait for all servos in the group to move

	# Define the target positions for all servos
	target_positions = {channel: servo_home[channel] for channel in servos}

	# Initialize sets of motors sequentially
	set_motor_angles([6, 7, 8, 9], target_positions)
	time.sleep(0.2)
	set_motor_angles([5, 4, 0, 1], target_positions)
	set_motor_angles([14, 15, 10, 11], target_positions)
	initialize_servo_angles()
	time.sleep(0.5)
	zero_imu()
	global prev_roll, prev_pitch
	prev_roll = prev_pitch = None

BODY_LEN = 0.186  # m
BODY_WID = 0.078  # m
L1, L2, L3 = 0.055, 0.1075, 0.130

# ===========================================================================
# Decoupled IK + Mirror approach
# Right legs (1, 3) use decoupled IK (q1 from y only, q2/q3 from x/z only).
# Left legs (0, 2) mirror negated servo deltas from their paired right leg.
# ===========================================================================

CHANNEL_MAP = {
	0:{1:9,  2:11, 3:15},
	1:{1:8,  2:10, 3:14},
	2:{1:6,  2:4,  3:0 },
	3:{1:7,  2:5,  3:1 },
}

# Loaded from the calibration file (kept in sync with MoveLib automatically)
_MAPPING_RIGHT = _CAL["mapping_right"]

_MIRROR_PAIR = {0: 1, 2: 3}
_MIRROR_SIGN = {1: -1, 2: -1, 3: -1}

_INV_RIGHT = {}
_ht_body0 = homog_transxyz(0,0,0) @ homog_rotxyz(0,0,0)
for _ri, _tf_fn in {1: t_rightfront, 3: t_rightback}.items():
	_T = _tf_fn(_ht_body0, BODY_LEN, BODY_WID)
	_INV_RIGHT[_ri] = ht_inverse(_T)

_RIGHT_CFG = {
	1: {'base': ( BODY_LEN/2, -BODY_WID/2, -0.16), 'scale': (-3/3.5*5/4, 3/2, 3/3.75)},
	3: {'base': (-BODY_LEN/2, -BODY_WID/2, -0.16), 'scale': (-3/2.5,     3/2, 3/3.75)},
}

_HOME_HIP = {}
_RIGHT_HOME_SERVO = {}
for _ri in (1, 3):
	_bx, _by, _bz = _RIGHT_CFG[_ri]['base']
	_P = _INV_RIGHT[_ri] @ np.array([_bx, _by, _bz, 1.0])
	_HOME_HIP[_ri] = (float(_P[0]), float(_P[1]), float(_P[2]))
	_q = ikine(float(_P[0]), float(_P[1]), float(_P[2]), L1, L2, L3, legs12=None)
	_cfg = _MAPPING_RIGHT[_ri]
	for _j in (1, 2, 3):
		_ch = CHANNEL_MAP[_ri][_j]
		_RIGHT_HOME_SERVO[_ch] = _cfg[_j]['sign'] * (_q[_j-1] * 180 / math.pi) + _cfg[_j]['offset']


def _decoupled_ikine(x4, y4, z4, l1, l2, l3, x4_home, y4_home):
	"""Fully decoupled IK: q1 from y only, q2/q3 from x/z only."""
	r_sq = x4_home**2 + y4**2 - l1**2
	if r_sq < 0:
		return None
	q1 = math.atan2(y4, x4_home) + math.atan2(math.sqrt(r_sq), -l1)

	r_sq_sag = x4**2 + y4**2 - l1**2
	if r_sq_sag < 0:
		return None
	D = (r_sq_sag + z4**2 - l2**2 - l3**2) / (2 * l2 * l3)
	if abs(D) > 1.0:
		return None
	q3 = math.atan2(-math.sqrt(1 - D**2), D)
	q2 = math.atan2(z4, math.sqrt(r_sq_sag)) - math.atan2(l3 * math.sin(q3), l2 + l3 * math.cos(q3))
	return (q1, q2, q3)


def _to_user_right(ri, theta_rads):
	cfg = _MAPPING_RIGHT[ri]
	return tuple(
		cfg[j]['sign'] * (theta_rads[j-1] * 180 / math.pi) + cfg[j]['offset']
		for j in (1, 2, 3)
	)


def _solve_decoupled(x_h, y_h, z_h, l1, l2, l3, x4_home, y4_home, *, max_up=2.0, min_down=0.1):
	"""Decoupled IK with reach-safe projection fallback."""
	vx, vy, vz = float(x_h), float(y_h), float(z_h)
	result = _decoupled_ikine(vx, vy, vz, l1, l2, l3, x4_home, y4_home)
	if result is not None:
		return result[0], result[1], result[2], (vx, vy, vz), 1.0

	steps = [k * 0.02 for k in range(1, int(max(1, max_up / 0.02)))]
	scales = []
	for d in steps:
		s1 = 1.0 - d
		s2 = 1.0 + d
		if s1 >= min_down:
			scales.append(s1)
		if s2 <= max_up:
			scales.append(s2)

	for s in scales:
		xs, ys, zs = vx * s, vy * s, vz * s
		result = _decoupled_ikine(xs, ys, zs, l1, l2, l3, x4_home, y4_home)
		if result is not None:
			if s > 1.0:
				s *= 0.995
				xs, ys, zs = vx * s, vy * s, vz * s
			return result[0], result[1], result[2], (xs, ys, zs), s

	return None, None, None, None, None


def iklegs_move(leg_offsets, step_multiplier=10, speed=10, delay=0.01):
	"""
	Move multiple legs together along straight-line paths in body-space.
	Right legs compute via decoupled IK; left legs mirror from paired right leg.
	"""
	def clamp(a):
		return max(0, min(270, a))

	max_steps = 0
	for dx, dy, dz in leg_offsets.values():
		max_steps = max(max_steps,
						abs(dx)*step_multiplier,
						abs(dy)*step_multiplier,
						abs(dz)*step_multiplier)

	MIN_STEPS = 1
	steps = max(MIN_STEPS, math.ceil(max_steps / max(1e-9, speed)))

	incs = {
		leg: (dx/steps, dy/steps, dz/steps)
		for leg, (dx, dy, dz) in leg_offsets.items()
	}

	for s in range(1, steps+1):
		step_movements = {}

		for leg_idx, (inc_x, inc_y, inc_z) in incs.items():
			ux = inc_x * s
			uy = inc_y * s
			uz = inc_z * s

			if leg_idx in _MIRROR_PAIR:
				uy = -uy

			ri = leg_idx if leg_idx in (1, 3) else _MIRROR_PAIR[leg_idx]
			cfg = _RIGHT_CFG[ri]
			xb = cfg['base'][0] + ux * cfg['scale'][0]
			yb = cfg['base'][1] + uy * cfg['scale'][1]
			zb = cfg['base'][2] + uz * cfg['scale'][2]

			P_body = np.array([xb, yb, zb, 1.0])
			P_hip = _INV_RIGHT[ri] @ P_body
			hx, hy, _ = _HOME_HIP[ri]

			q = _solve_decoupled(P_hip[0], P_hip[1], P_hip[2], L1, L2, L3, hx, hy)
			if q[0] is None:
				continue
			q1, q2, q3, _, _ = q
			user_deg = _to_user_right(ri, (q1, q2, q3))

			if leg_idx in (1, 3):
				for joint, tgt in enumerate(user_deg, start=1):
					ch = CHANNEL_MAP[leg_idx][joint]
					step_movements[ch] = tgt - servo_angles[ch]
			else:
				for j in (1, 2, 3):
					ch_R = CHANNEL_MAP[ri][j]
					ch_L = CHANNEL_MAP[leg_idx][j]
					delta_R = user_deg[j - 1] - _RIGHT_HOME_SERVO[ch_R]
					target_L = servo_home[ch_L] + _MIRROR_SIGN[j] * delta_R
					step_movements[ch_L] = target_L - servo_angles[ch_L]

		for ch, delta in step_movements.items():
			new = clamp(servo_angles[ch] + delta)
			servos[ch].angle = new
			servo_angles[ch] = new

		time.sleep(delay)

def enable_servos():
	output_enable.off()
	print("Servos enabled")

def disable_servos():
	lcd.clear()
	output_enable.on()
	for channel in servo_channels:
		pca.channels[channel].duty_cycle = 0  # Set the PWM signal to 0

# Global flag to track walking state
is_walking = False
is_sitting = False
is_kneeling = False
is_handstand = False
is_walking_backward = False
is_turning_right = False
is_turning_left  = False
is_amble = False
is_live_ik   = False
is_limp = False
is_fetal = False
prev_roll, prev_pitch = None, None

def create_gui():
	walkspeed = 15
	global walk_button, is_walking, sit_button, is_sitting, kneel_button, is_kneeling
	global is_handstand, is_amble, is_live_ik, prev_roll, prev_pitch
	global turn_left_button, turn_right_button, back_button
	global limp_button, unlimp_button, seizure_button
	global companion_flow_button, compan_shake_button

	window = tk.Tk()
	window.title("Robot Control")

	# Corndog dark theme (visual only — set before widgets are created)
	from corndog_theme import apply_theme
	apply_theme(window)

	# Fullscreen (Esc toggles out)
	window.attributes("-fullscreen", True)
	window.bind("<Escape>", lambda e: window.attributes("-fullscreen", False))

	# A container frame that fills the window
	root = tk.Frame(window)
	root.grid(row=0, column=0, sticky="nsew")
	window.rowconfigure(0, weight=1)
	window.columnconfigure(0, weight=1)

	# --- Responsive sizing -------------------------------------------------
	# We’ll compute font + padding from actual screen size.
	window.update_idletasks()
	sw = max(640, window.winfo_screenwidth())
	sh = max(480, window.winfo_screenheight())

	# Font size roughly scales with min(screen dims)
	# Tune these numbers if you want bigger/smaller.
	base = min(sw, sh)
	font_size = max(10, int(base * 0.025))      # ~2.5% of min dimension
	padx = max(8, int(sw * 0.010))              # 1% of width
	pady = max(6, int(sh * 0.008))              # 0.8% of height

	btn_font = ("Helvetica", font_size, "bold")

	# Decide how many columns the main menu grid should use based on width.
	# (More width -> more columns -> fewer rows -> less chance of offscreen.)
	if sw >= 2400:
		MAIN_COLS = 6
	elif sw >= 1800:
		MAIN_COLS = 5
	elif sw >= 1300:
		MAIN_COLS = 4
	elif sw >= 900:
		MAIN_COLS = 3
	else:
		MAIN_COLS = 2

	# How many columns to use for context-only views (Sit / Companion stages).
	# Keeping this lower makes large buttons.
	CONTEXT_COLS = min(3, MAIN_COLS)

	# --- Button bookkeeping ------------------------------------------------
	# We store buttons in two groups:
	# 1) main_buttons: participate in the main grid menu
	# 2) context_buttons: not shown in main menu; used by show_only(...)
	main_buttons = []      # list of tk.Button
	context_buttons = []   # list of tk.Button

	def make_button(text, command, *, include_in_main=True):
		b = tk.Button(
			root,
			text=text,
			command=command,
			font=btn_font,
			wraplength=int(sw / MAIN_COLS * 0.85),  # allow wrapping for long labels
			justify="center"
		)
		# Ensure consistent feel
		b.configure(padx=padx, pady=pady)

		if include_in_main:
			main_buttons.append(b)
		else:
			context_buttons.append(b)
		return b

	def _grid_buttons(buttons, cols):
		"""
		Grid a given list of buttons in a uniform table layout.
		Clears any existing grid placements first.
		"""
		# remove all current placements
		for w in root.grid_slaves():
			w.grid_remove()

		# configure columns to share space
		for c in range(cols):
			root.columnconfigure(c, weight=1, uniform="btncols")

		# give rows weight too so layout expands nicely
		# (we’ll set weights for rows we actually use)
		needed_rows = (len(buttons) + cols - 1) // cols
		for r in range(needed_rows):
			root.rowconfigure(r, weight=1, uniform="btnrows")

		# place buttons
		for i, b in enumerate(buttons):
			r = i // cols
			c = i % cols
			b.grid(row=r, column=c, sticky="nsew", padx=padx, pady=pady)

		window.update_idletasks()

	def show_all():
		"""Show main menu grid (only main buttons)."""
		_grid_buttons(main_buttons, MAIN_COLS)

	def show_only(*widgets):
		"""Show only the specified widgets in a grid (context view)."""
		# Preserve ordering passed in
		_grid_buttons(list(widgets), CONTEXT_COLS)

	# --- Original helpers, adapted ----------------------------------------
	def hide_others(active_btn):
		"""
		Legacy helper used by movement toggles: show ONLY the active button
		so user has a big Stop button.
		"""
		show_only(active_btn)

	# ------------------- Callbacks -------------------
	def ambletest():
		global is_amble
		if not is_amble:
			is_amble = True
			lcd.lcd("Ambling")
			amble_button.config(text="Stop Ambling")
			window.update()
			hide_others(amble_button)
			testingloop()
		else:
			is_amble = False
			lcd.lcd("Reseting to     Normal")
			iklegs_move({0:(0,0,0), 1:(0,0,0), 2:(0,0,0), 3:(0,0,0)})
			lcd.clear()
			amble_button.config(text="Test Amble")
			show_all()
			window.update()

	def testingloop():
		if not is_amble:
			return
		n=0.3
		h=6
		d=6
		iklegs_move({0:(-0.03+0.04,0,0.01*h), 1:(-0.01+0.04,0,0), 2:(-0.03,0,0), 3:(-0.05,0,0)}, step_multiplier=20, delay=0.1)
		time.sleep(n)
		iklegs_move({0:(0+0.04,0,0.01*h/2),      1:(-0.02+0.04,0,0), 2:(-0.04,0,0), 3:(-0.06,0,0)}, step_multiplier=20, delay=0.1)
		time.sleep(n)
		iklegs_move({0:(-0.01+0.04,0,0), 1:(-0.03+0.04,0,0), 2:(-0.05,0,0), 3:(-0.03,0,0.01*h)}, step_multiplier=20, delay=0.1)
		time.sleep(n)
		iklegs_move({0:(-0.02+0.04,0,0), 1:(-0.04+0.04,0,0), 2:(-0.06,0,0), 3:(0,0,0.01*h/2)}, step_multiplier=20, delay=0.1)
		time.sleep(n)
		iklegs_move({0:(-0.03+0.04,0,0), 1:(-0.05+0.04,0,0), 2:(-0.03,0,0.01*h), 3:(-0.01,0,0)}, step_multiplier=20, delay=0.1)
		time.sleep(n)
		iklegs_move({0:(-0.04+0.04,0,0), 1:(-0.06+0.04,0,0), 2:(0,0,0.01*h/2),    3:(-0.02,0,0)}, step_multiplier=20, delay=0.1)
		time.sleep(n)
		iklegs_move({0:(-0.05+0.04,0,0), 1:(-0.03+0.04,0,0.01*h), 2:(-0.01,0,0), 3:(-0.03,0,0)}, step_multiplier=20, delay=0.1)
		time.sleep(n)
		iklegs_move({0:(-0.06+0.04,0,0), 1:(0+0.04,0,0.01*h/2),     2:(-0.02,0,0), 3:(-0.04,0,0)}, step_multiplier=20, delay=0.1)
		time.sleep(n)
		window.after(0, testingloop)

	def walk():
		global is_walking, is_walking_backward
		is_walking_backward = False
		if not is_walking:
			is_walking = True
			lcd.lcd("Walking")
			walk_button.config(text="Stop Walking")
			window.update()
			hide_others(walk_button)
			move_motors({10: -20, 4: 20, 1: 35, 15: -35}, speed_multiplier=walkspeed)
			move_motors({11: -20, 5: 20, 1: -35, 15: 35}, speed_multiplier=walkspeed)
			walking_loop()
		else:
			is_walking = False
			lcd.lcd("Reseting to     Normal")
			move_motors({11: 20, 5: -20, 0: -35, 14: 35}, speed_multiplier=walkspeed)
			move_motors({10: 20, 4: -20, 0: 35, 14: -35}, speed_multiplier=walkspeed)
			lcd.clear()
			walk_button.config(text="Start Walking")
			show_all()
			window.update()

	def walking_loop():
		if not is_walking:
			return
		lcd.lcd("Walking 1/4")
		move_motors({11: 40, 5: -40, 0: -30, 14: 30}, speed_multiplier=walkspeed)
		lcd.lcd("Walking 2/4")
		move_motors({10: 40, 4: -40, 0: 30, 14: -30}, speed_multiplier=walkspeed)
		lcd.lcd("Walking 3/4")
		move_motors({10: -40, 4: 40, 1: 30, 15: -30}, speed_multiplier=walkspeed)
		lcd.lcd("Walking 4/4")
		move_motors({11: -40, 5: 40, 1: -30, 15: 30}, speed_multiplier=walkspeed)
		window.after(0, walking_loop)

	def walk_backwards():
		global is_walking, is_walking_backward
		is_walking = False
		if not is_walking_backward:
			is_walking_backward = True
			lcd.lcd("Backwards")
			back_button.config(text="Stop Backwards")
			window.update()
			hide_others(back_button)
			move_motors({10: -20, 4: 20, 1: 35, 15: -35}, speed_multiplier=walkspeed)
			move_motors({11: -20, 5: 20, 1: -35, 15: 35}, speed_multiplier=walkspeed)
			walking_loop_backwards()
		else:
			is_walking_backward = False
			lcd.lcd("Reseting to     Normal")
			move_motors({11: 20, 5: -20, 1: 35, 15: -35}, speed_multiplier=walkspeed)
			move_motors({10: 20, 4: -20, 1: -35, 15: 35}, speed_multiplier=walkspeed)
			lcd.clear()
			back_button.config(text="Walk Backward")
			show_all()
			window.update()
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

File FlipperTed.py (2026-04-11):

#!/usr/bin/env python3
#FlipperTed.py
import asyncio
import json
import time
import threading
from dataclasses import dataclass
from typing import Callable, List, Optional, Sequence

from evdev import InputDevice, list_devices, ecodes, categorize, KeyEvent

import main as bot  # change if needed


# ----------------------------
# Flipper device matching
# ----------------------------
NAME_MATCHES = ("flipper", "keynote", "control")


def is_flipper_dev(path: str) -> Optional[InputDevice]:
    try:
        dev = InputDevice(path)
    except Exception:
        return None
    name = (dev.name or "").lower()
    return dev if any(s in name for s in NAME_MATCHES) else None


# ----------------------------
# LCD writer (non-blocking, coalesced)
# ----------------------------
LCD_WIDTH = 16

def _fit16(s: str) -> str:
    s = (s or "").replace("\n", " ")
    if len(s) >= LCD_WIDTH:
        return s[:LCD_WIDTH]
    return s.ljust(LCD_WIDTH)

class LCDWorker:
    """
    Dedicated thread that performs LCD I/O so evdev handling never blocks.
    Coalesces updates: if you press DOWN 5 times fast, we only write the latest.
    """
    def __init__(self):
        self._lock = threading.Lock()
        self._event = threading.Event()
        self._stop = False
        self._pending: Optional[str] = None
        self._thread = threading.Thread(target=self._run, daemon=True)

    def start(self):
        self._thread.start()

    def stop(self):
        self._stop = True
        self._event.set()
        self._thread.join(timeout=1.0)

    def show_two_lines(self, line1: str, line2: str):
        msg32 = _fit16(line1) + _fit16(line2)  # no newline; 32 chars wraps on 16x2
        with self._lock:
            self._pending = msg32
        self._event.set()

    def clear(self):
        with self._lock:
            self._pending = " " * (LCD_WIDTH * 2)
        self._event.set()

    def _run(self):
        while not self._stop:
            self._event.wait()
            self._event.clear()

            # Grab latest pending message, discard older
            with self._lock:
                msg = self._pending
                self._pending = None

            if msg is None:
                continue

            try:
                bot.lcd.lcd(msg)
            except Exception:
                # Don't crash the controller if LCD glitches
                pass


lcdw = LCDWorker()


# ----------------------------
# Motion step DSL
# ----------------------------
class Step:
    def run(self) -> None:
        raise NotImplementedError


@dataclass
class Move(Step):
    movements: dict
    speed: int = 10
    delay: float = 0.01

    def run(self) -> None:
        bot.move_motors(self.movements, delay=self.delay, speed_multiplier=self.speed)


@dataclass
class Sleep(Step):
    seconds: float

    def run(self) -> None:
        time.sleep(self.seconds)


@dataclass
class Call(Step):
    fn: Callable[[], None]

    def run(self) -> None:
        self.fn()


@dataclass
class Repeat(Step):
    n: int
    steps: Sequence[Step]

    def run(self) -> None:
        for _ in range(self.n):
            for st in self.steps:
                st.run()


def MOVE(movements: dict, *, speed: int = 10, delay: float = 0.01) -> Move:
    return Move(movements=movements, speed=speed, delay=delay)

def SLEEP(seconds: float) -> Sleep:
    return Sleep(seconds=seconds)

def CALL(fn: Callable[[], None]) -> Call:
    return Call(fn)

def REPEAT(n: int, *steps: Step) -> Repeat:
    return Repeat(n=n, steps=list(steps))


@dataclass
class Motion:
    label: str
    steps: Sequence[Step]


# Prevent overlapping actions if center is spammed
MOTION_LOCK = threading.Lock()


def run_motion(m: Motion) -> None:
    with MOTION_LOCK:
        lcdw.show_two_lines(f"RUN: {m.label}", "...")
        try:
            for st in m.steps:
                st.run()
        finally:
            # leave redraw to menu afterwards
            pass


# ----------------------------
# Persistent state (survives process restarts)
# ----------------------------
STATE_FILE = "/tmp/queue_state.json"
RECONNECT_MEMORY_SECONDS = 5 * 60  # 5 minutes


def load_state(num_motions: int):
    """
    Read saved state from disk if it's within the reconnect window.
    Returns (index, servo_angles_or_None).
    servo_angles is None if the state is expired/missing, meaning a cold start.
    """
    try:
        with open(STATE_FILE, "r") as f:
            data = json.load(f)
        saved_at = data.get("saved_at", 0)
        index = data.get("index", 0)
        # JSON keys are always strings, so convert back to int
        servo_angles = {int(k): v for k, v in data.get("servo_angles", {}).items()}
        elapsed = time.time() - saved_at

        if elapsed <= RECONNECT_MEMORY_SECONDS and 0 <= index < num_motions and servo_angles:
            print(
                f"Warm reconnect: resuming index {index} "
                f"(saved {elapsed:.0f}s ago)."
            )
            return index, servo_angles
        else:
            print(
                f"State expired or invalid (saved {elapsed:.0f}s ago) — cold start."
            )
    except (FileNotFoundError, json.JSONDecodeError, KeyError):
        print("No valid saved state — cold start.")
    return 0, None


def save_state(index: int) -> None:
    """Write current index, servo angles, and timestamp to disk."""
    try:
        # servo_angles keys are ints; JSON needs string keys
        angles = {str(k): v for k, v in bot.servo_angles.items()}
        with open(STATE_FILE, "w") as f:
            json.dump({"index": index, "saved_at": time.time(), "servo_angles": angles}, f)
    except OSError as e:
        print(f"Warning: could not save queue state: {e}")


def restore_servo_angles(saved_angles: dict) -> None:
    """
    Push saved angles directly into the servos and bot.servo_angles
    WITHOUT physically moving anything — the robot is already in this pose.
    """
    for ch, angle in saved_angles.items():
        bot.servo_angles[ch] = angle
        bot.servos[ch].angle = angle
    print("Servo angles restored from saved state.")
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

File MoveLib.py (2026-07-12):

# MoveLib.py  (v2)
# ---------------------------------------------------------------------------
# Corndog MoveLib (single-file, no "resolve symbols"):
# - Includes the hardware + IK code directly (PCA9685 servos + BNO08X IMU + IK)
# - Includes a headless gait engine loop using the same tick-style process as gait_engine_app.py
# - Includes "emotions" (sit/unsit, kneel/unkneel, shake, dance)
#
# v2 changes (all opt-in / toggleable, defaults preserve v1 behavior unless noted):
#   MOTOR/IK LAYER
#   - SERVO_WRITE_DEADBAND: skip redundant I2C writes when a servo barely moved
#   - MOVE_EASING: optional cosine ease-in/out for move_motors interpolation
#   - speed_mode (kwarg or global SPEED_MODE): move_motors/iklegs_move slam every
#     servo straight to its final target in one write — no interpolation, no
#     synchronizing legs to finish together. For jumps etc.
#   - iklegs_move inner loop no longer builds a numpy vector per leg per step
#     (hip transform unrolled to scalar math; ~identical output, less CPU)
#   GAIT ENGINE
#   - real-dt phase advance (wall-clock measured, not assumed 50 ms) -> commanded
#     speeds now mean what they say. NOTE: this is THE change that may shift the
#     feel of your calibrated speeds slightly.
#   - finish-the-step: on a zero command the engine settles all feet to stance
#     before freezing (no more foot left hanging until the neutral reset)
#   - velocity slew limiting (toggle): ramps between snapped stick velocities
#   - central step-length clamp (toggle): scales (vx,vy,wz) together so no leg
#     ever silently saturates its own IK reach -> straighter fast walking
#   - soft-touchdown z profile (toggle, DEFAULT OFF): raised-cosine swing that
#     lands with ~zero vertical speed instead of max-speed slap
#   - inactivity neutral-reset delay is configurable (default lowered 1.5 -> 1.0 s)
#   - set_gait_option(key, value): one string-keyed entry point so the Steam Deck
#     (or anything else) can live-tune every knob above plus step_hz, swing_frac,
#     step_height, speed_scale, height_offset, imu comp, gait type, and the
#     joystick speed constants.
#
# Key behaviors:
# - gait_command(vx, vy, wz):
#     * nonzero starts the gait scheduler thread
#     * zero settles the step (if enabled), stops the gait scheduler thread and
#       (after INACTIVITY_RESET_S of inactivity) resets legs to neutral
# - stop_gait(schedule_inactivity_reset=False):
#     * stops gait WITHOUT scheduling the reset (use this for emotions)
# ---------------------------------------------------------------------------

from __future__ import annotations

import time
import math
import threading
import heapq
from dataclasses import dataclass
from typing import Callable, Dict, Tuple, Optional, Any

import board
import busio
import numpy as np
from gpiozero import OutputDevice
from adafruit_pca9685 import PCA9685
from adafruit_motor import servo

from adafruit_bno08x.i2c import BNO08X_I2C
from adafruit_bno08x import (
	BNO_REPORT_ACCELEROMETER,
	BNO_REPORT_GYROSCOPE,
	BNO_REPORT_MAGNETOMETER,
	BNO_REPORT_LINEAR_ACCELERATION,
	BNO_REPORT_GRAVITY,
	BNO_REPORT_ROTATION_VECTOR,
	BNO_REPORT_GAME_ROTATION_VECTOR,
	BNO_REPORT_GEOMAGNETIC_ROTATION_VECTOR,
)

from spot_micro_kinematics.utilities.transformations import homog_transxyz, homog_rotxyz, ht_inverse
from spot_micro_kinematics.utilities.spot_micro_kinematics import (
	t_rightback, t_rightfront, t_leftfront, t_leftback, ikine
)

import sys
from pathlib import Path
_REPO_ROOT = Path(__file__).resolve().parent
sys.path.insert(0, str(_REPO_ROOT))            # for `lcd` / `drivers`
sys.path.insert(0, str(_REPO_ROOT / "tools"))  # for corndog_config
from lcd import lcd_library as lcd  # type: ignore
from corndog_config import load_calibration as _load_calibration  # noqa: E402


# =============================================================================
# Small helpers
# =============================================================================
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

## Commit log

2026-04-08 Recovered repo after git object corruption; fixed IK
    [BottomLong.stl, CornDog holder Elbow.stl, CornDog holder Wrist.stl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]
2026-06-17 Proud Lidar stuff
2026-07-12 Add installer, calibration tools, config system, guides
2026-07-12 Fixed connection bugs for flipper and steamdeck
    [StartupLCD.py, SteamDeckCommunication.py, corndog_config.py]

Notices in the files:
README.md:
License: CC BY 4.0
